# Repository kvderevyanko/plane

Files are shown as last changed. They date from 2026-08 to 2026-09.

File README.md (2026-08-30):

# LR1600 — FPV aircraft CAD project

Параметрический проект самолёта LR1600. Базовая единица геометрии — миллиметр.
Единственный редактируемый источник инженерных параметров —
`config/aircraft.yaml`; подробности геометрии крыла — в `docs/wing.md`.
`generated/` и `build/` содержат только производные артефакты; универсальный
CAD toolchain — в `cad/`.

## Быстрый запуск

```bash
./tools/build.sh
./tools/test.sh
```

Команды используют локальное окружение `.tools/conda/lr1600-cad` и создают
только воспроизводимые файлы в `build/`. Если окружение ещё не создано, см.
`environment/README.md`.

Перед физическим производством прочитайте `docs/laser-workflow.md` и выполните
проверки. Успешный экспорт не является разрешением на резку.

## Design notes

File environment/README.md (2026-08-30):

# CadQuery environment

`environment.yml` is the reproducible specification for CadQuery and the
libraries actually used by this project. The project-local prefix is
`.tools/conda/lr1600-cad` and is intentionally ignored by Git.

Create it without touching system Python:

```bash
CONDA_PKGS_DIRS="$PWD/.tools/conda/pkgs" \
  /home/kirill/miniforge3/bin/mamba env create --prefix "$PWD/.tools/conda/lr1600-cad" \
  --file environment/environment.yml
```

The convenience scripts select this prefix. No `conda init` is required.

For the reproducible airfoil-analysis executable on Linux amd64, run:

```bash
bash ./tools/bootstrap-xfoil.sh
```

It downloads the pinned Debian XFOIL 6.99.dfsg+1-3 package, verifies its
documented checksum, and extracts it only into ignored `.tools/apps/xfoil`.

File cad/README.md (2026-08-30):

# CAD source

Source models live here; output belongs only in `build/`. `common/` contains
calibration geometry, while `wing/`, `fuselage/`, and `tail/` are reserved for
aircraft assemblies. Every model must use millimetres.

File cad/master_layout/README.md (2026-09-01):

# Master-layout reference model

`model.py` creates a visual CadQuery reference of configured aircraft geometry
and, when supplied, selected commercial-hardware installation envelopes from
`config/hardware.yaml`.  It uses the common aircraft
coordinate system: root leading-edge datum at `(0, 0, 0)`, `+X` aft, `+Y`
right, and `+Z` up, in mm.

The thin rendered wing is not a structural skin model; its `0.25 mm` display
thickness only makes CadQuery tessellation deterministic.  The model never
adds a fuselage skin or inferred component volume.

The typed rough-field reference adds only wheel/floor envelopes, main-gear
hardpoint points, the 13-in propeller-clearance cases and three forward
tail-linkage route lines.  None is production gear/linkage CAD or a
structural/load release.

MAC and its leading-edge position are read via the corresponding `WingConfig`
properties.  The trapezoid matches the existing centred planform.  A CG band
is drawn only when the typed `cg.initial_envelope.status` is
`initial_design_assumption` and has both configured MAC fractions.  Generated
PNGs are disposable downstream inspection artifacts.

Commercial envelopes are bounding boxes or a propeller disk, not detailed CAD
models, fuselage skin, or procurement approval. The high-current route and
antenna keep-outs are display references only. The selected battery is
deliberately *not* added as a clearance-passed hardware envelope: its rail,
hatch and removal path remain blocked pending defensible CG/mass-moment
closure. The pre-existing aircraft-config battery study envelope remains
visible and is not a claim that a physical pack can be removed.

Explicitly `known` mass-ledger entries appear as labelled coordinate markers.
They are point references only, not inferred physical envelopes. `tbd` entries
are intentionally omitted from the drawing and remain visible through the
mass-properties calculator's unresolved list.

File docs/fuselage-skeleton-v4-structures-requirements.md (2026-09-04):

# LR1600 Fuselage Skeleton & Longeron Convergence v4 — structural contract

**Scope:** dry-fit CAD gate for the plywood/carbon basic skeleton only. This is not a release of the complete fuselage, gear, battery installation, motor installation, or boom clamps. It retains the v3 mass topology and the station set in `config/aircraft.yaml`; it does not give credit to the foam shell, tooling, or any later subsystem.

The active assembly is the two lower keel/shear webs, two side shear webs, eight transverse formers at X = -285, -170, -55, +65, +130, +200, +285 and +365 mm, any hatch rail strictly needed to avoid an open skeleton, and four actual 5 x 3-mm carbon longerons. Every listed plywood body shall be a placed extrusion of the exact kerf-free profile exported to DXF. A CAD construction box, a face-only placeholder, or a generic mate record cannot satisfy this contract.

## Datum and stock convention

Aircraft coordinates are X aft, Y starboard, Z up. The current 5 x 3-mm stock orientation is fixed for this pass:

| Stock dimension | Aircraft direction | Nominal extent |
| --- | --- | ---: |
| length | X | lower: -475…+365; upper: -170…+410 mm |
| 5-mm face | Y | 5.0 mm |
| 3-mm face | Z | 3.0 mm |

Thus a longeron feature may not silently rotate the stock to 3 mm in Y and 5 mm in Z. CAD shall expose the final solid cross-section at every support. Nominal saddle/slot sizes equal nominal stock and sheet thickness; laser-fit clearance is established only by the existing material/kerf coupon at CAM.

## Required Method-A build sequence

The following is the only accepted sequence for this subsystem. The CAD validator must test the stated translation for each moving instance against the already-installed active solids at a sufficient set of intermediate poses. The final pose may contact only the feature-specific contacts named in its joint records.

| Step | Moving instances | Nominal insertion | Required final condition |
| --- | --- | --- | --- |
| A1 | `FUS-LONGERON-LOWER-L/R` | locate on datum jig; no skeleton present | Straight, continuous lower stock at final Y/Z datum. |
| A2 | each transverse former | descend in -Z onto/open around lower stock | Each lower notch admits its already-installed rail without forcing it; former remains removable before web closure. |
| A3 | `FUS-KEEL-L/R` | continuous +X threading from forward of their final X start | Each web passes every intended former feature without cutting through, bending, or moving a former. |
| A4 | `FUS-SIDE-L/R` | continuous +X threading from forward of their final X start | Each side web passes only its intended former features; the upper route remains unclosed. |
| A5 | `FUS-LONGERON-UPPER-L/R` | continuous +X translation from forward of X=-170 | Each rail traverses every aligned, top-open frame notch and reaches X=+410 as one uncut length. |
| A6 | only necessary hatch/closure rails | declared direction after A5 | No closure traps either upper rail before its full insertion. |

Equivalent paths are permissible only if they preserve A1–A6's key facts: lower rails precede surrounding plywood; complete upper rails enter after formers/webs; no rail is inserted through a closed captive hole. A start pose shall be outside every final active primary solid by at least the moving part's full cross-section. Report the number and spacing of sampled poses and the minimum non-permitted clearance; sampled final contacts do not count as a clearance failure when the named contact is geometrically correct.

## Longeron support and bond contract

Every support is an actual cut feature on an actual placed plywood instance, with a unique ID. A valid support record has:

- longeron instance ID and actual cross-section at the support;
- plywood instance ID and feature ID;
- support type (`lower_open_notch`, `upper_open_notch`, `web_land`, or `bonded_face`), world X interval, and whether it is critical;
- the contact faces, their contact length and width, calculated nominal bond area, and a no-overlap fit result; and
- the assembly step at which it is engaged and the compatible insertion axis.

### Lower pair

Because lower longerons are installed first, transverse-former features must be **bottom-open U notches** (or an equally open edge saddle) that can be descended over the rail in A2. A closed 5 x 3-mm rectangle is forbidden. The lower keel/webs subsequently threaded in A3 shall provide continuous real bond faces/support lands along their overlap with each lower rail. The final model must not represent a rail simply intersecting the web volume: a rail surface must meet a declared, non-overlapping plywood support face.

### Upper pair

Because upper longerons enter in A5, every former they traverse must have a **top-open** 5-mm-Y by 3-mm-Z edge notch/saddle. Its open mouth must remain clear throughout the +X insertion path; no laterally offset notch, closed hole, tab, crossbar, hatch rail, or adjacent web can obstruct the swept 5 x 3-mm prism. The side web must supply a declared continuous upper-edge land and/or a declared continuous vertical bond face. The former notches locate the rail; the side web land carries the distributed web-to-longeron bond. Their geometry must touch the carbon without CSG penetration other than the feature-specific bonded-face tolerance.

For either pair, the nominal local plywood ligament from a notch root to the nearest free edge/window shall be at least one sheet thickness plus 3 mm, and shall be reported at every station. Where the former carries a high-load continuity bay (+65…+200 gear, -55…+65 wing-transfer, +285…+365 boom/motor), the corresponding notch root must retain at least 6 mm of continuous plywood in the load-carrying frame rail; a window may not terminate at that root. These are geometry/handling minima, not a substitute for proof or material allowables. A smaller ligament is a v4 skeleton blocker unless a dedicated local structural analysis and a revised prototype proof plan are supplied.

### Continuity requirements

The machine report shall sort supports by X and calculate unsupported intervals between their *contact intervals*, rather than claim a continuous land from a part name. Acceptance is:

- maximum unsupported gap <=10 mm outside critical bays;
- zero unsupported gap in X=-55…+65, +65…+200, and +285…+365 mm;
- no square-ended support/bond interruption inside a critical bay; and
- no discontinuity at a former caused by a window, slot, or different local placement.

The lower paths must be covered through X=-475…+365 and upper paths through X=-170…+410. End regions may taper only outside critical bays and must state remaining bond/contact length. No strength allowable is to be inferred until existing carbon-to-prepared-birch coupons have been tested. Expected first failures remain bond peel at an unprepared charred edge, plywood splitting at a notch root, or local carbon crush from an overly narrow caul—not global carbon tensile failure.

## Former-to-web joint contract

The active baseline contains **30** former/web through-joints if current web extents are retained:

- eight formers x two lower keel/webs = 16 joints;
- seven formers at X=-170…+365 x two side webs = 14 joints.

`FUS-FMR-X-285` has no side-web joint while present side webs start at X=-170; this absence must be explicitly recorded, not represented by an orphan feature. If CAD changes a web extent, it must update this expected joint count and explain the structural consequence.

Each of these 30 joints requires one exact instance-level record containing:

1. joint ID, tab-bearing instance/feature and slot-bearing instance/feature;
2. joint type, structural purpose, nominal web thickness and receiver-slot narrow dimension;
3. final world centreline/face coordinates and tolerance used;
4. declared insertion direction and assembly step;
5. remaining ligament on both members; and
6. exactly bounded permitted tab engagement/contact volume.

The continuous web may furnish a locally named through-tab at a station, but the CAD profile must contain distinguishable geometry for that feature; the label `perimeter-tab` alone is not sufficient. The former slot must be the specific profile cutout at the same world Y/Z location. In particular, a local 2-mm slot dimension does not establish mating until placed web and former feature centres/planes agree in world coordinates.

For a 2-mm web, the slot narrow dimension is 2.0 mm nominal. A 3-mm former may receive that same 2-mm web: former thickness is along X and does not change web/slot mating thickness. Tabs and slots are registration and shear transfer only after prepared bonded faces are present; do not credit an isolated thin tongue as a primary load path. No tab may terminate at a window corner or leave zero-width material. Every actual tab and slot participates in exactly one active joint, except a separately labelled jig-only feature; there must be zero duplicate counterparts and zero active orphan features.

## Collision and dry-assembly gate

The active-v4 collision set is restricted to placed formers, placed keel and side webs, active hatch/closure rails if any, and four carbon solids. Gear, nose, battery, wing, motor and boom items must be excluded by explicit subsystem filtering, not by whitelisting their collisions.

For each final or intermediate pose, classify contact only by a narrow feature-level permission:

- a named tab/slot engagement;
- a named carbon saddle/bond face;
- a named plywood bonded lap/butt face; or
- a named datum-jig contact during A1 only.

Whole-part-pair permissions are prohibited. All other active primary-primary intersections greater than 0.01 mm3 fail. The report must list both IDs, pose/step, intersection volume, and either contact ID or `UNEXPLAINED`. Acceptance total is **zero** `UNEXPLAINED` intersections. Face contact with zero volume is acceptable only if named in the contact record.

The results must include a machine-readable manifest and readable report with 30-joint accounting; each longeron support/bond interval and gap; all six Method-A paths; and collision classifications. It shall also export diagnostic views of full skeleton, one lower notch, one upper notch, one former/web joint, and any failed collision.

## Prototype-cuttable rule for v4

A skeleton part may be labelled **`PROTOTYPE CUTTABLE — SKELETON SUBSYSTEM ONLY`** only when its own profile/STEP identity, placed feature mates, ligaments, insertion path, and active collision checks pass. This grants only a first dry-fit/proof skeleton article. It does not release complete fuselage or change authoritative 398-g aircraft ledger.

Before adhesive is mixed, retain existing kerf calibration coupon and pass sacrificial 5 x 3-mm stock through all four real routes. Remove laser char to sound birch on every structural bond face, abrade/de-dust carbon, and record actual adhesive/cure procedure. Failed fit is corrected in CAM kerf settings or nominal source geometry as appropriate; it is never corrected by filing an untracked primary feature.

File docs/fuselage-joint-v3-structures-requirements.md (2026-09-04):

# LR1600 Fuselage Joint & Assembly Convergence v3 — structural-joint requirements

**Status: engineering input to CAD convergence; not a cutting release.**  This
note freezes the v2 mass architecture as a 457.997-g candidate.  Added mass up
to 20 g is justified only where this note calls for an actual bearing land,
tab, doubler, retainer, or local load-transfer feature.  Kerf remains a laser
job setting; no kerf offset belongs in the nominal profiles.

The source constraints are `config/aircraft.yaml`, `docs/landing-gear.md`,
`docs/fuselage-proof-plan.md`, and the v2 gate record.  In particular, the
main box must survive one-main 121 N vertical and 35 N lateral/longitudinal
proof; the nose index must survive 60 N vertical and 35 N lateral/
longitudinal proof; P60B restraint proof is 44.4 N in each principal direction.

## Non-negotiable CAD contract

For every physical joint the model shall carry a machine-readable record with:

- a unique joint ID, each actual instance ID, one tab/key/bond-face feature ID
  on each participant, station, nominal material thickness, and insertion
  axis;
- a joint type (`through_tab`, `blind_notch`, `bonded_saddle`, `clamp`, or
  `bearing`), structural purpose, and permitted overlap/contact volume; and
- a declared dry-build step.  A part may enter only while its insertion path is
  clear of parts already installed, apart from the joint's declared contact.

At nominal geometry, a tab thickness shall equal the receiving sheet's nominal
thickness and the slot's narrow dimension shall equal that thickness.  The
laser-process clearance is applied downstream after the 2-mm/3-mm coupons are
measured.  A joint is invalid if it is metadata only, uses a generic rectangle
unrelated to a counterpart, leaves a zero-width ligament, or needs a forced
elastic deformation to assemble.

The validator shall report, per joint: feature existence; one-to-one partner;
nominal width/thickness match; placement alignment; translated insertion-path
clearance; and residual ligament.  It shall also report every primary-solid
intersection.  Only declared tab/slot material, declared bonded faces, and
declared clamp/bearing contacts are permitted; unexplained intersection volume
above 0.01 mm3 is a failure.  Generic quantity placement by an arbitrary Y
increment is prohibited: each left/right, fore/aft or stacked instance needs
its own physical placement and role.

## A. Skeleton and longerons

Use the existing station set `-285, -170, -55, +65, +130, +200, +285, +365`
mm.  Each transverse former must have real, paired features to the longitudinal
members it actually stabilises; do not cut full-width members across the
230 x 125-mm hatch opening.  A former-to-keel/side-web tab may be sacrificial
for alignment, but it cannot be credited for primary shear unless it has a
continuous surrounding ligament and bond land.

Choose one coherent assembly method: **recommended Method A** is lower
longerons on the datum jig, central formers/keels and side webs located around
them, then upper longerons installed through open aligned notches before the
hatch/closure rails close the path.  The model must prove this order.  It may
not mix a closed captive slot at one station with a slide-through procedure.

Each 5 x 3-mm carbon longeron requires a real 5-mm-wide by 3-mm-deep locating
groove/saddle or an explicitly open insertion notch, with a continuous plywood
bond face.  The lower pair remains X=-475…+365 and the upper pair
X=-170…+410.  No unsupported gap or square-ended support interruption is
allowed in the gear bay, wing-transfer bay, or motor/boom bay.  The CAD report
shall list, for each of four paths, start/end, every supporting part,
uninterrupted bond-face length, and the largest unsupported gap.  Acceptance:
no gap in those critical bays; any non-critical gap is <=10 mm and explicitly
explained.  The actual 5 x 3 solid must clear the receiving geometry except
for its declared saddle/bond contact and must pass the full declared insertion
translation.

## B. Main-gear cassette

The cassette is a closed, serviceable double-shear assembly between X=+65 and
+200, tied to both lower longerons.  It needs separately identifiable port and
starboard doublers, front and aft spreaders, upper and lower closure/load-path
webs, and two real clamp lands.  Every spreader/closure must tab into its web
or be a clearly documented bonded lap with adequate overlap; an intersecting
solid is not a joint.  The load path to show in CAD is wheel/leg root -> clamp
lands and side doublers -> front/aft spreaders and closures -> lower longerons
and adjoining shear webs.

Use an explicit *single-leg specimen* solid, with root width, clamp length and
bolt centres stated in the manifest.  The clamp pocket reference gap shall be
4.0 mm.  The only valid variant stacks are:

| GFRP specimen | Total shim in pocket | Check |
| --- | ---: | --- |
| 4.0 mm | 0.0 mm | 4.0 + 0.0 = 4.0 mm |
| 3.5 mm | 0.5 mm | 3.5 + 0.5 = 4.0 mm |
| 3.0 mm | 1.0 mm | 3.0 + 1.0 = 4.0 mm |

If shims are split across faces, their sum—not their nominal part label—must
meet the table.  A shim must never be fitted to the 4.0-mm leg or stacked such
that the assembly exceeds the pocket gap.  Generate three mutually exclusive
validation configurations; they are not simultaneously installed.

For each clamp fastener, emit the actual hole diameter, centre-to-each-free-
edge distance, net ligament in load direction, plywood thickness at the hole,
bearing-land width, washer/spreader outside diameter, and whether the leg is
between two real shear plates.  The washer envelope must remain on solid
material; it may not bridge a window, slot or thin remnant.  These values are
inputs to the proof article, not a substitute for the required 121/35/35-N
test.  Main-leg replacement acceptance: remove clamp hardware, translate the
leg along the stated axis out of the cassette, insert each specimen, and
reinstall hardware with all fuselage primary parts remaining installed.

## C. Fixed nose index

The nose module at X=-285/-170/-55 shall contain a physically modelled metal
tang envelope, a plywood index block, two actual doublers, capture bolt/pin,
clearance at the bolt head/nut, and a removal direction.  The 12-mm key is
acceptable only if a 12-mm-wide tang has two flats engaging matching plywood
index faces.  The bolt retains the strut; it is not the yaw reaction feature.

The validator shall show: tang translated through the hatch/insertion path to
the seated position; zero forbidden overlap; the two key flats bearing on the
index faces under either yaw sense; capture hardware installed after seating;
and reverse translation after hardware removal.  Report capture-hole diameter,
edge distances, local bearing land, remaining ligament and expected first
failure (key-face crush, plywood split, or bolt-bearing migration).  The proof
gate remains 60 N vertical then 35 N lateral and 35 N longitudinal.

## D. Battery bay and hatch

The 155 x 75 x 28-mm P60B dummy must be the solid used for all positions:
X=-387.5, exact 24% target, wheels-25% target, -370 nominal, and -332.5 mm.
At each position report collision-free status against every structural part;
rail support and declared stop contact are allowed contacts, not blanket
exemptions.  Include a conservative connector/service envelope and state its
dimensions and side of exit.

Forward stop, adjustable aft stop and both strap anchor paths must attach to
real rails/formers/webs through actual tabs, bolts or bonded faces.  The model
must show accessible buckle/strap routing and access to tighten/release the aft
fine clamp.  Neither hatch, pack shrink-wrap, wiring nor a printed part gets
structural credit.  The complete path for each independent stop/strap path is
required to be capable of the full 44.4-N proof reaction.

Removal must be checked as individual poses, not a union-box reservation:
installed -> connector-service displacement -> +Z 20 -> +Z 50 -> +Z 100 ->
clear of the real 230 x 125-mm hatch.  Check all five rail positions or explain
why a worst-case pair bounds the others.  Each pose must be collision-checked
against hatch rails, formers, longerons, stops, avionics reservations and the
connector envelope.  Do not suppress a member class globally; every permitted
contact must name the physical contact face.

## E. Wing transfer, motor and booms

At the present wing-interface stations, show discrete plywood frames/webs and
any necessary local 3-mm doublers transmitting fuselage-side wing reactions to
both upper and lower longerons plus adjacent side webs.  Do not create a solid
plate/box in lieu of these parts.  This CAD task does not approve the wing; its
interface remains conditional on the existing wing proof.

The motor crossmember must be an assembly of laser parts: crossmember members,
real slots/tabs into longeron-connected structure, a central cable/cooling
opening, and a removable plate with a candidate motor envelope.  Plate bolts
must be accessible and the plate must translate aft (or another explicitly
stated direction) without prop-adapter trapping.  The provisional proof screen
remains 15.1 N axial, 1.26 N m torque and 0.64 N m inertia bending; a single
thin tongue, adhesive-only feature or printed tab may not be credited for
torque.

At X=+285/+365 and Y=+/-230, boom placeholder frames must be actual placed
profiles with no collision with longerons or the motor structure.  They remain
`NOT RELEASED`; no tube/saddle clamp load or mass credit is permitted until
tube, liner, fastener and coupon evidence exists.

## Required assembly record and CAD acceptance

The CAD package shall contain a stepwise dry-build record: lower-longeron jig;
central formers/keels; side webs; upper longerons; gear cassette; battery rails
and stops; nose index; wing-transfer closure; motor structure; remaining
closures/rails.  Each entry names inserted instance(s), axis, already-installed
collision set, joint IDs, adhesive timing and an alignment measurement.

Before structural prototype cutting, pass all of the following:

1. every declared tab and slot has exactly one real counterpart; no orphan;
2. all four real carbon solids fit and are installable by the single stated
   method;
3. all three gear-leg configurations insert/remove and satisfy their stack gap;
4. the keyed nose tang inserts/removes and has geometric anti-rotation faces;
5. P60B placements and removal poses pass without unexplained collision;
6. motor plate removes and all primary contacts/overlaps are classified; and
7. contact report has zero unexplained primary overlaps above 0.01 mm3.

Only parts whose own interfaces pass may be marked `PROTOTYPE CUTTABLE`.
Passing CAD permits cutting a proof-test structural prototype, not flight use;
proof coupons and installed proof remain required.

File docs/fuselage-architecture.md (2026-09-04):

# LR1600 Fuselage Architecture v1

**Status:** preliminary structural architecture and packaging estimate, not production CAD, a measured mass, material allowable, or flight release. All stations use the wing-root-LE datum; +X is aft. The 2,600-g integration case is used. Wing geometry and its structural concept are unchanged.

## Selected architecture and envelope

Selected: a repairable plywood-frame/four-longeron semi-monocoque fuselage. Laser-cut internal structure, local birch hardpoint boxes and continuous carbon longerons carry load; removable foam/light-composite shell, hatches, printed camera bezel and printed cable guides are secondary. None of those secondary parts receives wing, boom, motor, battery or landing-load credit. A 14-g lower skid is sacrificial and replaceable.

Preliminary outer envelope is **X=-500 to +410**, W=**180** (Y=+/-90), H=**190** (about Z=-95...+95); a replaceable motor plate reaches X=+430. The 910-mm body prioritises serviceability and no-ballast CG closure over minimum frontal area. This nose length is an explicit pitch-inertia penalty, not an aesthetic choice.

| Station X | Function | Primary material |
|---:|---|---|
| -285 | nose-gear / front lower-keel **partial U-web** station | 2-mm birch; printed camera bezel secondary |
| -170 | lower-keel / battery-side-rail **partial U-web** station | 2-mm birch/local non-ferrous fasteners |
| -55 | wing-forward shear frame | 3-mm birch web, 2-mm flanges |
| +65 | wing-rear shear frame / gear-box front | 3-mm birch |
| +130 | main-gear reaction frame | 3-mm birch double-shear box |
| +200 | gear-box rear / equipment frame | 3-mm web, 2-mm flange |
| +285 | boom/motor torque web | 3-mm birch/carbon-wrap interfaces |
| +365 | motor plate / boom-clamp frame | 3-mm birch and replaceable plates |

Intermediate shape formers are 2-mm birch. The **two lower 5x3-mm pultruded-carbon longerons** run continuously from X=-475 to +365, tying the forward battery-stop/keel box into the wing box; the upper pair runs X=-170 to +410. 2-mm birch side rails and the hatch perimeter are primary tension/shear members around the battery opening. Thus no battery stop discharges into unsupported shell. Exact supplier data, scarf detail and adhesive overlap remain coupon/CAD gates. Sand laser-charred structural bond faces to sound wood, abrade and de-dust. Nominal CAD contains no kerf compensation; a measured-kerf coupon controls finished slots.

## Primary paths

| Interface/event | Primary load path | Never primary |
|---|---|---|
| Wing attachment | wing root spar/D-box hardpoints -> paired 3-mm saddle/shear frames at -55/+65 -> longerons and central box | foam, hatch, one former, printed saddle |
| Twin booms | provisional indexed +285/+365 alignment and motor-bridge stations; final primary bending transfer remains a dedicated boom/wing-interface CAD and proof gate | adhesive-only tube joint, foam, one bolt |
| Main gear | GFRP leg -> +65/+130/+200 double-shear box -> lower longerons and upper closure web | shell, foam, printed fairing |
| Nose gear | strut bearing tube -> -285/-170/-55 lower-keel box -> lower longerons | camera tray/nose shell |
| Motor | fixed 25-g fuselage cross-member/base -> paired shear keys -> boom clamp frames and central torque web; separate replaceable plate/adapter then bolts to base | printed tab, thin tongue, adhesive alone |
| Battery | broad 2-mm cradle -> 3-mm end stops/two straps -> lower longerons and hatch-perimeter side rails | cells, shrink-wrap, hook-and-loop alone, hatch |
| Body bending/torsion | four longerons carry bending; plywood frames and local diagonal 2-mm webs close central box | foam shell alone |

Boom axes remain Y=+/-230, outside the 180-mm body. The fuselage supplies a central bridge and clamp frames, not a narrow wall carrying the full 460-mm separation. Use two indexed stations >=80 mm apart, non-crushing liners and two anti-rotation shear features per boom. Fixture axes/tail during bonding. Preliminary targets: each boom axis +/-0.5 mm at both clamps, station separation +/-0.5 mm, and differential tail incidence <=0.25 deg after proof.

## Battery and service access

The P60B 6S1P integration envelope is **155 x 75 x 28 mm**, a feasible two-cells-long by three-cells-wide 21700 arrangement including interconnect, insulation, connector exit and modest assembly allowance; it is not a verified pack drawing. The prototype rail has **55-mm** useful travel, X=-387.5...-332.5, extending the prior forward limit by 5 mm without lengthening the nose. With the fixed-nose gear ledger, required pack centres are -384.78/-373.40/-362.03/-339.27 mm for 24/25/26/28% MAC respectively. The X=-370.0 nominal reference yields 25.30% MAC; exact 24% and 25% are physically reachable. The complete moving pack envelope is X=-465...-255. Final measured-CG release is mandatory.

Use a top hatch with a provisional **230 x 125-mm clear opening** (approximately X=-472.5...-242.5), two mechanical latches and a secondary retained strap. Its CAD removal sweep clears the pack at both rail limits, but physical dummy-pack service proof remains required. No full-width former crosses this opening: the -285/-170 stations are lower-keel partial U-webs only, while the birch perimeter/side rails close the load path. The pack lifts up after guarded disconnect; it does not pass servo horns/high-current wire. Full-area non-compressive cradle, 3-mm stops and two 20-mm straps take the 6-g retention assumption with 1.5 proof: a 503-g pack needs **29.6 N operational / 44.4 N proof per principal direction**. Treat each complete stop/strap path as capable of the full proof load rather than claiming a failed path shares it. At nominal X=-370.0 the battery CG ledger moment is **-186,110 g mm**. Proof with an inert dummy in six directions.

FPV occupies a protected lower-front cassette centred at X=-215, Z=+5, vertically separated from the pack. Optional 25--60-g HD camera uses a removable tray centred at X=-175; its break-away printed cradle is not a nose-impact path. FC/equipment trays are X=+80...+210 with an upper service hatch. GNSS uses the non-ferrous upper support at X=-105, Z=+95; preserve a compass keep-out from the nose strut and high-current wiring.

## Materials and mass

| Group | Central mass g | Function |
|---|---:|---|
| 2-mm frame, keel, shear webs | 70 | primary shape/shear/torsion |
| Carbon longerons/local wraps | 34 | primary bending continuity |
| 3-mm birch wing/gear/boom hardpoints | 70 | bearing/clamp/concentrated reactions |
| Foam/light-laminate shell and extended-nose reinforcement | 62 | enclosure only; local bumper support |
| Battery cradle, rails, hatch, straps/latches | 55 | retention/service |
| Fixed motor base/cross-member | 25 | fuselage-side primary interface; excludes removable plate/adapter |
| Equipment/camera trays | 18 | secondary support |
| Replaceable skid/bumper | 14 | ground protection |
| Adhesive, inserts, fasteners, chafe allowance | 50 | installation allowance |
| **Fuselage structural group, no removable gear** | **398** | **design estimate** |

The single point submitted to the current CG ledger is **398 g at X=-1.6 mm** (moment -636.8 g mm), not measured. The removable motor plate/adapter/positive prop-retention group is a separate **50-g propulsion-ledger item** and is explicitly excluded from this 398-g fuselage group; only its fixed 25-g base/cross-member remains here. Plausible mass interval is 365--440 g, driven by plywood density, carbon section, adhesive uptake, latches and proof outcome. Do not remove 3-mm gear/boom boxes or continuous longerons only to meet target mass. Expected early failures: plywood bearing/splitting, unprepared-bond peel, local carbon crushing at clamp, gear-leg root delamination and motor-plate bolt bearing; global foam-shell failure must remain non-critical.

## Motor and cooling interfaces

The fixed base accepts a separate replaceable 50-g plate/adapter/positive-retention group for the current 50-mm-diameter, 70-mm installed-length, <=180-g motor class without locking an SKU. The preliminary proof envelope is **15.1 N axial thrust** (1.5 x a 10.1-N screening thrust), **1.26 N m torsion** (1.5 x a 0.84-Nm screening torque), and **0.64 N m motor-inertia bending moment** (4 g on 180 g at a 90-mm CG offset). These are bounded design screens, not measured motor data. Before release, proof selected hardware to measured static thrust, 1.5 times measured torque and 4-g motor inertia at true CG offset; inspect plate twist, bolt bearing, clamp slip, carbon crushing and prop alignment.

Provide a baffled lower-front inlet for battery/FC, a protected side inlet at X=+190 for ESC/regulator flow, and upper/aft outlets at X=+275...+340. Outlet free area >=1.25x inlet after guards. Recessed mesh is allowed only when temperature testing shows acceptable pressure loss; exits must not ingest grass. Use grommets, strain relief and removable covers at all wire/antenna penetrations.

## Release gates

1. Coupon actual birch bearing/net-section, carbon clamp liner and prepared bond, then proof a representative wing/boom/gear bay.
2. Proof installed main/nose hardpoints vertically and laterally to `landing-gear.md`, with no permanent set, slip, cracking, delamination or incidence loss.
3. Proof battery cradle/rails/stops/latch in six directions; repeat removal after proof.
4. Demonstrate dummy-prop clearance at maximum compression, 20-mm rut and 8-deg tail-low attitude.
5. Enter weighed parts and measured CG before calling the integration case a flight release.

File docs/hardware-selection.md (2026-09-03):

# LR1600 hardware baseline v1

> Superseded for active fuselage/gear integration by
> [`config/hardware.yaml`](../config/hardware.yaml) and
> [`cg-integration-v2.md`](cg-integration-v2.md). This retained document is
> historical evidence for the rejected 14-in/KDE/P30B branch, not a current
> component selection or mass source.

Status: selected preliminary hardware, **not** a procurement release. Aircraft
requirements remain in `config/aircraft.yaml`; exact commercial facts, masses
and installation envelopes have one versioned source: `config/hardware.yaml`.
Every commercial source was retrieved on 2026-09-01.

## Propulsion

| Item | Preliminary selection | Evidence and disposition |
|---|---|---|
| Propeller | APC LP14010E / 14x10E Thin Electric, two blade, 34.02 g | [APC](https://www.apcprop.com/product/14x10e/) gives geometry, mass and hub. [UIUC Volume 4](https://m-selig.ae.illinois.edu/props/volume-4/propDB-volume-4.html) provides Ct/Cp/efficiency data. |
| Fallback prop | APC13010E / 13x10E | [Horizon/APC listing](https://www.horizonhobby.com/product/electric-propeller-13-x-10e/APC13010E.html); lower-clearance fallback, but less convincing 90-km/h forward-flight screen. Not in the mass baseline. |
| Motor | KDE Direct KDE4215XF-465 | [Manufacturer](https://www.kdedirect.com/products/kde4215xf-465): 465 KV, 4–6S LiHV, 195 g bare, 48.2 x 36 mm, 62 A / 1375 W for 180 s with >=5 mph cooling. |
| ESC | Hobbywing Skywalker 60A V2 / 30216101 | [Official manual](https://www.hobbywing.com/en/uploads/file/20250930/64b726be7a56c9f415385f77683cdc46.pdf): 3–6S, 60 A continuous, 80 A peak, 68 g, 73 x 30 x 12 mm. Integral 5-V BEC is unused. |

The APC 14x10E central forward-flight screen is about
4.5/4.9/5.58/6.27 krpm at 60/70/80/90 km/h. Pitch speed is
68.6/74.7/85.0/95.5 km/h and tip speed 83.8/91.2/103.9/116.6 m/s. These are
kinematics, not a safe-RPM approval. The 490/670-W electrical screen uses a
static-coefficient proxy around 6.6/7.33 krpm and 26/32 N only.

KDE has no manufacturer map for a 6S APC14x10E pusher combination. Before
purchase or flight, bench-test current, RPM, thrust and motor/ESC temperature
in the installed pusher geometry; capture the current APC RPM limit too. True
pusher installation has APC lettering facing aircraft front and a positively
retained, nutted adapter. Motor reversal cannot correct a prop mounted with
the wrong airfoil face.

The 14-inch disk remains in the 460-mm boom-spacing screen; 15 inch remains
excluded from baseline until a new geometry/dynamic-clearance analysis.

## Battery and protection

Selected preliminary cell is [Molicel INR-18650-P30B](https://www.molicel.com/wp-content/uploads/Product-Data-Sheet-of-INR-18650-P30B-80111-1.pdf), not a marketplace cell. A 6S2P pack gives:

| Quantity | Value |
|---|---:|
| Typical nominal / 80%-usable energy | 129.6 / 103.68 Wh |
| Complete pack estimate | 624 g = 564 g cells maximum + 60 g construction allowance |
| 685-W screening load at 21 V | 32.62 A pack / 16.31 A per cell |
| Documented cell continuous limit | 30 A to 80 °C cutoff |
| First-order 50%-SOC cell-only sag | 0.277 V/cell; 1.66 V/6S |

The documented 17-mOhm DCIR is used only for the 50%-SOC cell calculation;
low-SOC, temperature, ageing, busbar and connector effects need a pack
load/sag/temperature test. 6S3P is a 150-Wh stretch (194.4 Wh typical,
155.5 Wh at 80%, roughly 926 g with construction allowance) and remains a
mass-risk alternative.

Architecture is balance-charge/monitoring-only with thermal sensing; there is
**no power-path BMS between pack and ESC**. A BMS transient disconnect is a
single-point propulsion loss. The future flight path is pack positive → fuse →
anti-spark/main disconnect → current sensor → ESC plus independent regulators.
Exact fuse, anti-spark connector, BMS and time-current validation remain TBD.
The [Littelfuse MEGA family](https://www.littelfuse.com/assetdocs/littelfuse-datasheet-mega-32v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) is a family reference, not a selected fuse.

## Controls and avionics

Baseline control count is two aileron, one elevator and two rudder servos:
four Hitec [D85MG](https://hitecrcd.com/d85mg-micro-32-bit-metal-gear-servo/)
at 21.9 g, 4.3 kgf-cm and 2.15-A stall each, plus Hitec
[HS-7245MH](https://hitecrcd.com/hs-7245mh-high-voltage-high-torque-metal-gear-coreless-mini-servo/)
at 34 g, 5.2 kgf-cm and 1.6-A stall. Aggregate hard stall is 10.2 A / 61.2 W
at 6 V: an electrical transient, not an average-power claim. Hinge-moment and
load-path validation are still required.

Dedicated 6 V is [Pololu D24V150F6](https://www.pololu.com/product/2882),
thermal-dependent 15 A nominal / 32-A instantaneous. Clean 5 V is
[Pololu D24V90F5](https://www.pololu.com/product/2866), thermal-dependent
4–8 A. Both need installed thermal validation; neither ESC BEC nor FC BEC
replaces the separated-rail design.

| Function | Preliminary selection |
|---|---|
| FC | Matek H743-WING V3, [manual](https://www.mateksys.com/downloads/H743-WING_Manual.pdf), 30 g; H743 WING family is [ArduPilot supported](https://ardupilot.ardupilot.org/plane/docs/common-autopilots.html). |
| GNSS/compass | Matek [M10-5883](https://www.mateksys.com/?portfolio=M10-5883), 9 g; keep >=100 mm from power/ESC/motor/ferrous parts; M10-L4-3100 fallback after failed compass survey. |
| RC | RadioMaster [RP3 Diversity ELRS](https://www.radiomasterrc.com/products/rp3-expresslrs-2-4ghz-nano-receiver), CRSF UART, 4.6 g. |
| Telemetry | Holybro [SiK V3](https://holybro.com/products/sik-telemetry-radio-v3), 23.5 g; legal 433/915 band TBD. |
| Airspeed | Matek ASPD-DLVR, 4 g; [compatibility source](https://www.mateksys.com/?page_id=7637), primary manual still required. |
| FPV | RunCam [Phoenix 2 Nano](https://www.runcam.com/download/Phoenix2-Nano/Phoenix_2_Nano_Manual_EN.pdf), 5 g; TBS [Unify Pro32 HV](https://www.team-blacksheep.com/media/files/tbs-unify-pro32-manual.pdf), 8.7 g. |

Hotel-load envelope is 7-W low, **16-W nominal** (hardware-backed design
estimate, not measurement) and 25-W high. GNSS/compass stays out of the
motor/ESC/high-current/VTX zones, receiver antennas are orthogonal and clear
of VTX, and VTX requires airflow plus legal setting. Provisional interfaces:
GNSS UART2 + I2C1, SiK UART7, CRSF UART6, airspeed I2C2; confirm the purchased
board revision before configuration.

## Gates remaining

- Motor–propeller pusher bench map, installed cooling and mount proof.
- Pack sag/temperature, fuse time-current, connector and anti-spark validation.
- Servo hinge moments, regulator transient/thermal test and linkage mass.
- Compass/RF survey, range, VTX legality/cooling and primary airspeed manual.
- Mass moments and actual battery/hatch geometry; current tray does not close CG.

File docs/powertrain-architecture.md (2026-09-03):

# LR1600 Powertrain Architecture, Battery & Avionics Packaging v1

> Historical 2,400-g energy screen. The active configuration is the P60B
> 6S1P / 13x10 preliminary integration branch in
> [`config/hardware.yaml`](../config/hardware.yaml); this document is not its
> mass or placement source.

`scripts/powertrain_architecture.py` is a reproducible architecture and
energy-screening model.  It writes `analysis/powertrain/summary.json` and
three inspection plots.  It does not select a motor, ESC, propeller, battery,
cell, connector, BEC or any commercial SKU.  `config/aircraft.yaml` remains
the sole editable aircraft source of truth; this document proposes only a
future typed-configuration contract after integration of the packaging study.

## Known

- Target aircraft mass is 2400 g.  The prior propulsion model has a central
  electrical propulsion reference of 135 W at 70 km/h and 197 W at 80 km/h;
  these are central CdA/efficiency cases, not measured flight powers.
- The existing requirement study uses 490 W as the adverse 4 m/s-climb
  integration screen and 670 W as a broader propulsion-only screen.  This
  study adds its nominal 15 W hotel estimate when calculating bus current.
- Twin-boom spacing is 460 mm.  The preceding clearance work admits 12--14 in
  study disks; 15 in does not fit the baseline geometry without a change.

## Design assumptions

- 4S uses 14.0 V and 6S uses 21.0 V as conservative loaded-voltage screen
  inputs.  Their fully charged voltages are 16.8 and 25.2 V.  These are not a
  pack discharge curve: selected cells must provide `V(SOC, I, T)`.
- Bus hotel low/nominal/high cases are 7 / 15 / 25 W at the battery terminals.
  They include estimated DC/DC loss, but no measured hardware consumption.
- The power lead study uses 0.5 m one way, 2 mOhm connector-pair resistance,
  copper resistivity 0.01724 ohm-mm²/m and a 2% wire-only loss target.
- Usable energy is 80% of nominal stored pack energy.  This is a reserve and
  unusable-energy study assumption, not a flight reserve policy.

## 4S versus 6S

At equal electrical power, 6S reduces current; it therefore reduces I²R lead
and connector heat, and enables the lower-KV motor region normally useful for
the existing 12--14 in pusher study.  This is not a claim that more series
cells are always better: 6S needs a 25.2-V-charged ESC and appropriate BEC/DC
converters, whereas 4S can use lower-voltage hardware.

| Case (includes 15 W nominal hotel) | Bus power | 4S current at 14.0 V | 6S current at 21.0 V |
|---|---:|---:|---:|
| 70 km/h central cruise | 150 W | 10.7 A | 7.2 A |
| 80 km/h central cruise | 212 W | 15.1 A | 10.1 A |
| 490 W climb integration screen | 505 W | 36.1 A | 24.1 A |
| 670 W broader screen | 685 W | 48.9 A | 32.6 A |

At the final broad screen, a 0.5-m one-way pair needs about 3.0 mm² copper
on 4S or 1.3 mm² on 6S to hold wire-only loss at 2%.  With a conservative
2.5-mm² study lead, losses are about 16.5 W (4S) and 7.3 W (6S), respectively;
connector-pair heat adds about 4.8 W and 2.1 W.  Harness length, temperature,
connectors and actual current must replace this screen before wire selection.

### Preliminary architecture direction

Use a **6S propulsion bus as an initial design assumption**, not a hardware
selection.  It makes the 670 W screen roughly 33 A instead of 49 A, giving a
meaningful margin in wiring, connector heating and Li-ion parallel-count
choices.  4S remains a fallback if actual motor/propeller mapping or packaging
evidence overturns this benefit.

## Propulsion motor and ESC requirements

The preferred propeller geometry and motor-map analysis remain separate from
this electrical calculation.  Electrical integration constrains their search:

- motor/propeller must demonstrate the 12--14 in clearance-compatible
  operating point, 60--90 km/h pitch-speed coverage and the propulsion study's
  actual thrust-versus-airspeed requirement;
- with a 6S bus, validate a lower-KV motor operating region rather than a
  catalogue maximum-W number; RPM, torque, shaft pattern and thermal map are
  still TBD;
- request at least 35 A measured installed continuous current capability and
  45 A short burst capability at 6S, with verified margin above 25.2 V;
- ESC cooling is a packaging requirement: it needs direct ram/ducted airflow,
  a short high-current route and a thermal demonstration at its installed
  location.  Telemetry is desirable for current, voltage, RPM/temperature if
  hardware supports it, but its protocol is TBD;
- active/freewheel control may reduce part-load ESC loss where supported; it
  is not assumed.  Prop braking must remain disabled unless its effect on a
  pusher installation, motor heating and recovery modes is tested.

Do not use an ESC BEC as the aircraft's assumed avionics supply.  Use a
dedicated 6-V servo regulator (provisionally at least 10 A continuous / 15 A
transient, pending servo count and measured stall currents) and an independent
clean regulated 5-V avionics rail.  This separates servo transients from FC,
GNSS, receiver and airspeed power.

## Hotel load and endurance sensitivity

The 7 / 15 / 25 W cases are **battery-bus continuous** design estimates.  The
servo group adds a separate provisional 48-W peak on its 6-V rail, which is a
BEC/transient test input and must not be counted as continuous endurance load
without a duty-cycle measurement.

At the central 70-km/h propulsion reference, the following are still-air
screening values, not promised endurance or range:

| Usable energy | Low 7 W: h / km | Nominal 15 W: h / km | High 25 W: h / km |
|---:|---:|---:|---:|
| 100 Wh | 0.70 / 49.2 | 0.67 / 46.6 | 0.62 / 43.7 |
| 150 Wh | 1.05 / 73.8 | 1.00 / 69.9 | 0.94 / 65.5 |
| 200 Wh | 1.41 / 98.5 | 1.33 / 93.2 | 1.25 / 87.4 |
| 250 Wh | 1.76 / 123.1 | 1.66 / 116.5 | 1.56 / 109.2 |

The generated result also includes all 60/70/80/90 km/h and low/nominal/high
combinations.  It uses `endurance = usable_Wh / (P_propulsion + P_hotel)`.
The previous propulsion model remains the authoritative place for its drag,
efficiency and headwind sensitivity assumptions.

## Li-ion versus LiPo battery direction

The study uses nominal **pack** specific-energy bands of 200--240 Wh/kg for
Li-ion and 150--190 Wh/kg for LiPo, then applies the common 80% usable-energy
assumption.  Thus a 200-Wh usable study system represents 250 Wh nominal and
roughly 1040--1250 g Li-ion or 1320--1670 g LiPo.  These are packaging/mass
study ranges, not actual pack masses.

| Usable energy | Li-ion estimated pack mass | LiPo estimated pack mass |
|---:|---:|---:|
| 100 Wh | 521--625 g | 658--833 g |
| 150 Wh | 781--938 g | 987--1250 g |
| 200 Wh | 1042--1250 g | 1316--1667 g |
| 250 Wh | 1302--1563 g | 1645--2083 g |

**Li-ion is the preliminary long-range direction**, conditional on data for
the actual cells, series/parallel grouping, low-SOC voltage sag and thermal
rise.  The 685-W broad screen is 2.3--5.8C at 250--100 Wh usable, respectively;
cell and parallel-count ratings must substantiate it.  **LiPo is the fallback**
when a suitably packaged Li-ion system cannot meet peak-current, sag or
temperature requirements.  Neither chemistry nor capacity has been selected.

## Typed source-of-truth assumptions adopted by integration

The integration has added the following preliminary assumptions to
`config/aircraft.yaml`.  They are requirements/envelopes, not selected
hardware or measured performance:

```yaml
propulsion:
  status: initial_design_assumption
  nominal_series_count: 6
  propeller: {diameter_min_mm: 330.2, diameter_max_mm: 355.6, pitch_min_mm: 228.6, pitch_max_mm: 254.0}
  motor: {kv_min_rpm_per_v: 365.0, kv_max_rpm_per_v: 570.0, continuous_current_a: 35.0, peak_current_a: 45.0}
electrical:
  propulsion_bus_nominal_voltage_v: 22.2
  propulsion_bus_loaded_min_voltage_v: 21.0
  avionics_logic_rail_v: 5.0
  servo_rail_v: 6.0
  hotel_load_low_w: 7.0
  hotel_load_nominal_w: 15.0
  hotel_load_high_w: 25.0
battery:
  chemistry_direction: li_ion_preliminary  # conditional on sag/thermal data
  usable_energy_preferred_min_wh: 100.0
  usable_energy_preferred_max_wh: 150.0
  mass_min_g: 520.0
  mass_max_g: 940.0
```

The source config separately carries a 100--150 Wh preferred packaging range
and 520--940 g conditional Li-ion mass envelope. The 100 Wh baseline maps to
521--625 g and the 150 Wh stretch case maps to 781--938 g using the explicit
80% usable fraction and 200--240 Wh/kg nominal-pack screen. That mass range
must not be treated as a procurement mass or a closed 2400-g mass budget; the
100 Wh case is the baseline and 150 Wh awaits mass/moment closure. The larger
200/250 Wh rows remain energy sensitivity cases rather than selected fuselage
requirements.

## TBD before hardware selection

- motor KV/RPM/torque map, propeller pitch/blade count and measured static and
  forward-flight thrust;
- selected cells/pack architecture, mass, dimensions, sag, thermal behaviour,
  BMS/protection, connector and charge policy;
- actual servo count, rail voltage, average/stall current, and BEC test data;
- exact FC/GNSS/RX/telemetry/VTX models, pin/resource map, radio frequencies
  and antenna geometry;
- final wiring lengths, conductor temperature rating, fuse/anti-spark choice,
  ESC/motor cooling, EMI/compass survey and installation tests;
- battery position range and resulting estimated configuration CG.

## Reproduction

```bash
./tools/cad-shell.sh scripts/powertrain_architecture.py
./tools/test.sh
```

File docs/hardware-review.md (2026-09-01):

# Independent review — hardware baseline v1

Review scope: evidence quality, ratings, battery model/protection, mass/CG,
and layout/removal honesty. Reviewer findings were dispositioned as follows.

| Finding | Disposition |
|---|---|
| Current X=0 ±30 mm tray cannot reach 24–28% MAC. | Accepted blocker. No new tray/hatch geometry is recorded; solver range and explicit no-closure output added. |
| 220.05-g central fuselage residual masks structural uncertainty. | Accepted. Low/central/high residual is now 389.96/220.05/50.14 g, so mass closure remains blocked. |
| CG documentation did not match generated calculation. | Fixed: current tray values are 166.15/173.95/181.75 mm. |
| Motor check implied evidence-closed capability. | Fixed: only partial KV/current screen passes; original mass envelope fails and 6S+APC operating point/continuous rating remain unvalidated. |
| Fixed-21-V sag calculation was not self-consistent. | Fixed with a cell-only constant-power root: 685 W at 21.6 V/102 mOhm gives 38.83 A, 17.64 V, 19.42 A/cell at 50% SOC. It increases the need for low-SOC/cold bench validation. |
| Prop map, FMEA, rail/servo authority, actual removal/collision are incomplete. | Accepted as procurement/fuselage gates. The analysis now labels prop data as a UIUC screening method and includes a three-motor shortlist; no false clearance, removal, hinge-moment or rail-thermal pass is claimed. |

Remaining high findings are therefore open, not waived: motor-prop pusher bench
map, APC RPM limit, ESC LVC/thermal behavior, pack build/sag/fuse test, FC
external-rail connection verification, rail-load/servo-hinge analysis,
compass/RF survey, real motor hub/adapter/wiring collision, and battery
retention/removal proof. The M10-5883 availability/EOL state must be checked at
procurement; its selected-preliminary status is not an availability guarantee.

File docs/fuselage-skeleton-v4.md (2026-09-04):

# LR1600 Fuselage Skeleton & Longeron v4 gate record

**Status: NOT CUTTABLE — v4 WIP retained.**  This document covers only the
basic skeleton and four 5x3-mm carbon longerons.  Gear, nose, battery, wing,
motor and boom systems were intentionally outside the gate.

## Independent CAD gate result

The active set has 12 plywood definitions, 12 placed instances and 30 declared
former-to-web joints (16 keel and 14 side).  DXF and STEP extrusion both derive
from `PartDefinition` for these active parts.  Those facts do not establish a
physical joint.

The independent CSG check found all 30 former/web joints overlapping in their
final placements, totalling about 886 mm3.  The v4 collision report hid them by
whole-part-pair permission rather than by an identified tab engagement volume.
Former extrusion direction and web-slot placement leave half the former through
the web; keel joints additionally have a Z mismatch.

Discrete independent translation sampling also finds both keel webs and both
side webs colliding with installed formers through their claimed +X insertion
paths.  Therefore Method A fails at the web-installation steps, irrespective of
the declared sequence metadata.

## Longeron-specific blockers

- Lower carbon-to-keel contact is a line contact, with no physical bond area.
  Claimed continuous support and 2,520-mm2 bond area per lower rail are not
  geometry-derived.
- Former notches engage only 1.5 mm of the intended 3-mm stock because their
  placed Z is offset from the declared feature.
- Upper rails can translate in sampled poses, but with zero nominal clearance
  and only 2-mm wide side-web contact; the reported 1,740-mm2/rail area is not
  supported by the solid geometry.

## Required corrective geometry

1. Generate the real tab/notch contours from the same placed feature datum as
   the report, then cut the exact nominal engagement without a whole-part
   collision whitelist.
2. Reposition or orient the former extrusion and each web so tab/slot volume is
   feature-specific and the non-engaged solid volume is disjoint.
3. Model bottom-open 5(Y)x3(Z) lower saddles and top-open upper saddles at the
   actual longeron coordinates; calculate support/bond area from faces.
4. Implement every Method A pose as a translated CSG collision check against
   the already-installed subset.  Report minimum clearance, not a metadata
   PASS.

Until these items pass, no active skeleton part has earned
`PROTOTYPE CUTTABLE — SKELETON SUBSYSTEM ONLY` and no dry-fit laser prototype
should be cut.

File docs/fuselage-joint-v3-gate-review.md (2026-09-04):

# Fuselage Joint & Assembly Convergence v3 — independent gate

**Status: REJECTED — complete plywood set is not cuttable.**

The v3 candidate preserved the lightened topology and reports 467.484 g, within
the 478-g joint budget.  This is not an accepted structural mass or centroid:
the assembly is not physically coherent.

## Independent deterministic findings

- 85 primary-to-primary intersections exceed 0.01 mm3; 63 have no declared
  mating relationship.  Intended contacts are not represented as feature and
  instance-level permissions.
- Former slots miss each longitudinal web in world coordinates.  The existing
  checks find a generic slot, not the stated feature, instance, alignment or
  remaining ligament.
- The four 5x3-mm carbon longerons have neither physical plywood saddles nor
  a valid insertion route: lower rods are separated from their keel webs and
  formers cut into the rods.
- Gear cassette pieces overlap rather than form a closed cassette.  There are
  no configured GFRP-leg solids, valid 4.0-mm pocket/shim stacks, bearing
  report, hardware envelope or replacement sweep.
- The nose tang/index and capture fastener are metadata rather than solids;
  index/doublers overlap.  Geometric anti-rotation and removal are unproven.
- Battery solid clears its five installed X positions, but rails, stops,
  anchors, clamps, strap/hardware access, connector and avionics service
  envelopes lack a real attached assembly.  Removal checks only the rail ends.
- Wing-transfer members are absent.  Motor plate and crossmember are separated
  by 39 mm; boom placeholders are absent from the placed assembly.
- Adhesive mass uses a fourfold longeron-land expression and must be recomputed
  only after real bond faces exist.  Generic structural-hardware ownership
  cannot yet be reconciled against landing-gear hardware.

## Required next geometric work

Replace the present profile/placement abstraction with feature-level geometry:
every actual tab, notch, saddle, bolt land and key needs an instance-level
counterpart, permitted contact volume and insertion path.  Then derive an
unexplained-collision report, a true sequential dry assembly, and only then
recalculate mass and centroid.  No part currently labelled `PROTOTYPE CUTTABLE`
has passed this gate.

## Checks performed

- `./tools/test.sh`: 166 passed, but declarations-only tests do not prove the
  listed physical conditions.
- `git diff --check`: passed.

Physical coupons/proof tests remain later gates; this rejection is based only
on resolvable CAD geometry and assembly conditions.

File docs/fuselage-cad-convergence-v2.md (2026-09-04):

# LR1600 Fuselage CAD Convergence v2 — gate record

**Status: NOT RELEASED — corrective WIP.**  This record deliberately does not
replace the `fuselage_structural_group` ledger entry (398 g) or its moment.

## Reconciliation snapshot

| Item | Mass (g) | Status |
| --- | ---: | --- |
| Architecture ledger estimate | 398.000 | Authoritative integration estimate; unchanged |
| WIP before convergence | 676.136 | Divergent profile/box model; invalid |
| Current profile-derived candidate | 457.997 | Not accepted for aircraft CG or manufacture |

The current candidate is 218.139 g below the WIP number.  Its derived
breakdown is 336.742 g birch, 66.030 g 5×3-mm carbon longerons, 20.225 g
adhesive allowance from 61,744 mm² declared bond land, and 35.000 g hardware:
16 g structural fasteners, 8 g hatch hardware, 6 g battery retention, and 5 g
fixed motor-interface hardware.  The removable motor plate/adapter is excluded
from this candidate because it is owned by the propulsion ledger.

The candidate centroid is X/Y/Z = -5.072 / +0.113 / -14.753 mm.  This value is
finite and mechanically derived from the current profile extrusions, but it is
**not credible for replacing the aircraft ledger** because the gate failures
below mean the placed CAD set is not a physical assembly.

## What v2 did establish

- `PartDefinition` is the common nominal source for DXF outline/cutouts,
  plywood extrusion and profile-volume mass rows; the manifest records profile
  hashes and part-instance mapping.
- Four 5×3-mm carbon longerons are present as stock solids at the preserved
  specified paths.
- The current hatch-rail placement gives a nominal 230×125-mm opening.
- The P60B solid is evaluated at -387.5, -384.78, -373.40, -370.0 and
  -332.5 mm, with a discrete withdrawal/cable envelope.  This is a CAD check,
  not a manufacturing release.
- Boom-saddle placeholders remain `NOT RELEASED` and are excluded from the
  flight-mass set and STEP assembly.

## Independent review blockers

The independent review found that the corrective model still has no verified
complementary tab/slot geometry: mates are largely metadata, several placements
either overlap or miss, and longerons/formers do not have validated locating
grooves.  It also found window/hardpoint conflicts, an unproven gear-cassette
load path, an unassembled nose tang/index box, and insufficient proof that
battery service clearances are contacts rather than excluded collisions.

Therefore all apparent `PROTOTYPE CUTTABLE` statuses are provisional model
labels only; a complete structural sheet must **not** be cut.  Required next
work is a placement-led feature model with complementary geometry, pairwise
collision/contact and edge-distance validation, then a new independent review.

## Aircraft-mass sensitivity

No wheels+FPV, skis+FPV, or wheels+FPV+45-g-HD replacement sensitivity is
published here.  Using the candidate mass/centroid would silently convert an
unaccepted CAD set into aircraft mass data.  After the mating and load-path
gates pass, calculate those three cases by replacing only the existing
398-g/(-1.6,0,0)-mm ledger item and report AUW, CG and battery X for 25% MAC;
no ballast assumption is permitted.

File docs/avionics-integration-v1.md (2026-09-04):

# LR1600 avionics, cooling and forward-controls integration v1

**Status:** preliminary packaging contract for the fuselage architecture.  It
uses the root-wing-leading-edge datum, with `+X` aft, `+Y` right and `+Z` up.
It is neither a wiring pinout nor an ArduPilot parameter file; exact FC board
revision and manufacturer documentation remain mandatory before wiring.

This document supersedes only the *physical-placement* assumptions for the
old tail-mounted Hitec servos.  The electrical direction, P60B pack study,
rail isolation and validation gates in
[electrical-rebaseline.md](electrical-rebaseline.md) remain applicable.

## Packaging stations and mass inputs

The following are centre-of-mass targets, in mm.  They are intentionally
specific enough for the next fuselage CAD study, while retaining a 10-mm
local adjustment allowance for brackets, hatches and cable exits.  No item is
credited as measured.

| Item | X | Y | Z | Mass (g) | Installation requirement |
|---|---:|---:|---:|---:|---|
| KST X08H V5 aileron servo, left/right | 135 | -450 / +450 | 0 | 8.0 each | Remains in the wing; direct short pushrod. |
| KST X08H V5 elevator servo | 110 | 0 | -15 | 8.0 | Removable central servo deck, output axis transverse. |
| KST X08H Plus V5 rudder servo, left | 110 | -32 | -15 | 9.6 | Independent output and independent pull--pull loop. |
| KST X08H Plus V5 rudder servo, right | 110 | +32 | -15 | 9.6 | Independent output and independent pull--pull loop. |
| Flight controller, isolated assembly | 125 | 0 | +15 | 30.0 | On rigid local shelf with controlled soft isolation; not on the gear plate. |
| Airspeed sensor | 150 | 0 | +15 | 4.0 | Same removable electronics shelf; pressure ports face aft/up and tubing is strain-relieved. |
| ELRS receiver | 95 | +48 | +20 | 4.6 | Serviceable side shelf; two antenna elements exit at 90 degrees. |
| SiK telemetry radio | 165 | -48 | +20 | 23.5 | Separate port-side antenna exit; regional band remains a procurement gate. |
| GNSS/compass | -105 | 0 | +95 | 9.0 | Non-ferrous upper mast or removable upper-shell pad. |
| FPV camera | -215 | 0 | +5 | 5.0 | Recessed nose cassette behind sacrificial bumper/window. |
| Optional Full-HD camera + isolated mount | -175 | 0 | +8 | 25--60 | Separate removable nose cassette; use its weighed mass in the CG ledger. |
| VTX | 250 | -48 | +20 | 8.7 | Port aft-side ventilated cassette; direct-bus filtered branch. |
| ESC (Skywalker 60A V2 envelope) | 285 | +42 | +5 | 68.0 | Starboard aft-side cooling duct, with short motor phase leads. |
| Servo DC/DC | 210 | +35 | 0 | 19.0 | Accessible power shelf; dedicated 6-V return trunk. |
| Logic 5-V DC/DC | 185 | +35 | 0 | 15.0 design estimate | Same shelf but separate clean output/return from servo rail. |
| Fuse, anti-spark/main disconnect and current sensor | 220 | 0 | 0 | 22.0 design estimate | Directly accessible after hatch opening; no discharge-path BMS. |

The five selected servos total **43.2 g** at `Xcg = 119.3 mm`, `Ycg = 0`,
`Zcg = -9.4 mm`.  This replaces the old 121.6-g Hitec five-servo set and its
tail locations; the old components/locations must not remain in any mass
ledger.

The first P60B pack must be entered as its weighed complete value.  The active
fuselage-prototype packaging contract is **503 g** and **155 x 75 x 28 mm**;
this overrides the smaller historical cell-block comparison envelopes in
`electrical-rebaseline.md`, which are not valid tray/removal geometry.  Its
rail position is deliberately owned by the CG closure, not by the avionics
layout.  Reserve a protected cable exit at the aft, lower-right corner of the
moving tray so that all pack positions leave at least 20 mm to the tray/hatch
edge and cannot pull on the connector.

## Forward-tail actuation

All three tail servos sit on a removable 2-mm birch-plywood servo deck carried
between structural fuselage frames; the deck itself is secondary and the
frames/longerons are primary.  Elevator and rudder outputs remain separate in
both mechanics and FC output assignment.  A removed hatch must expose servo
horn screws, output connectors, tensioners and the first guide without
removing the wing or battery.

| Route | Preliminary architecture | Length / supports | Mass allocation and mass centroid |
|---|---|---|---|
| Elevator | 3.0 x 1.0-mm carbon tube, M2 threaded end fittings, horn ball links; no flexible Bowden as the primary compression member. | Nominal centreline length 610 mm from `X=110` to tail; guide at <=150-mm unsupported spacing, with one axial-expansion/slip allowance at the aft guide. | 12 g at `X=415 mm`, including tube, end fittings, guides and horn hardware. |
| Left rudder | Own 0.45-mm 7x7 stainless closed-loop pull--pull cable, PTFE-lined fuselage transition and non-compressive boom guide clips. | About 720-mm one-way route (servo to boom transition then fin), so 1.44 m cable per rudder; guides <=150 mm, bend radius >=25 mm; tensioner at accessible tail horn. | 8 g at `X=414 mm`, including cable, liners, tensioner, exits and horn hardware. |
| Right rudder | Identical but physically independent route. | Same as left; no cross-coupling or shared bellcrank. | 8 g at `X=414 mm`. |

Thus the **forward-tail mechanical linkage allocation is 28 g at `X=414.4
mm`**.  Aileron pushrods, horns and wing-local installation are a separate
**12 g at `X=135 mm`** allocation.  The complete five-surface mechanical
linkage allocation is consequently **40 g at `X=330.6 mm`**.  Servo extension
leads, receiver leads and connectors belong to the wiring allocation, not to
these figures; reserve **10 g at `X=185 mm`** for control-specific leads only
if the master wiring item has not already absorbed them.

The 3-mm tube has an approximate pinned-column Euler load of 68 N at a 200-mm
free length (using 70-GPa carbon axial modulus), but only about 30--40 N of
control compression should be credited until the actual tube, guides and horn
geometry are tested.  The <=150-mm elevator guide pitch provides a sensible
preliminary margin.  Guides must locate laterally without crushing the tube;
test for no perceptible lost motion after thermal cycling, water/dust exposure
and 1000 full-control cycles.  Cable pull--pull is selected over a long
rudder-pushrod because it remains in tension, is tolerant of the boom route,
and has externally inspectable/tensionable failure points.  Its tension and
friction must be checked at both summer and winter temperatures.

## Electrical segregation and harness contract

Functional topology is:

```text
P60B pack -> fuse -> anti-spark/main disconnect -> current sensor -> ESC -> motor
                 |-> 6-V servo DC/DC -> five servos
                 |-> isolated clean 5-V DC/DC -> FC, GNSS, RX, telemetry, airspeed
                 `-> filtered direct-6S video branch -> FPV camera, VTX
```

- Battery-to-ESC positive and negative must be paired/twisted from tray exit
  to ESC, with no separately wandering return. The reserved route is about
  **674 mm one-way**. It therefore uses **4.0-mm2 silicone copper** and a
  voltage-qualified **680--1000-uF low-ESR capacitor at the ESC input**;
  final capacitance follows the selected ESC manual and a bench ripple test.
  With 4.3 mOhm/m representative copper resistance, the 1.348-m loop screens
  at 5.8 mOhm: about 0.20 V / 7.1 W at 35 A and 0.26 V / 11.8 W at 45 A.
  Measure installed resistance, connector temperature and ripple; do not
  infer a continuous-current approval from this screen.
- Keep motor phase wires <=120 mm from ESC to motor where packaging permits;
  twist the three phases.  Keep both phase and battery-current loops out of
  the GNSS mast, receiver antenna and video-signal routes.
- Run the clean 5-V output and I2C/UART loom on the upper centre/port chase;
  run servo 6-V and PWM as a paired trunk on the centre-lower chase.  The FC
  is the signal reference point: servo return current must return to the 6-V
  regulator, not through the FC's 5-V ground trace.
- Use locking connectors, chafe sleeves where a harness crosses a former, and
  a service loop only in low-current signal leads.  No high-current lead or
  antenna may be able to enter the propeller disk after a latch or tie fails.

Required geometric keep-outs, to be verified by powered testing rather than
treated as a guarantee:

| Sensitive item | Required preliminary keep-out |
|---|---|
| GNSS/compass at `(-105, 0, +95)` | At least 100 mm from motor, ESC, power leads/current sensor, VTX and ferrous landing-gear/motor/boom hardware; keep its mast and screws non-ferrous. |
| ELRS diversity antenna elements | Two 65-mm active elements at 90 degrees, with >=80 mm from VTX antenna and >=50 mm from high-current or motor phase wires.  Keep both outside carbon shielding where possible. |
| VTX antenna | Port aft-side exit, clear of propeller disk and >=100 mm from ELRS active elements; use 400 mW or less until the installed legal/RF/thermal check passes. |
| Airspeed tubing | One continuous supported run from probe to sensor; no radius <20 mm, no pinch under hatch, and no low-point water trap.  Leak-test after every wing/fuselage service event. |

Neither the H743-WING V3 PWM mapping nor the UART/I2C labels in legacy
documents are a permission to wire by assumption.  Before wiring, capture
the exact board revision/manual, then make a pin/resource record for the five
PWM outputs, CRSF, GNSS, telemetry, airspeed, current/voltage sensing,
battery monitor scaling, and all RC/GPS/airspeed/low-energy failsafe actions.

## Deliberate cooling architecture

The proposed openings are side-mounted above the wheel-spray and grass line;
they are not belly scoops.  Each has an internal 45-degree water/drip baffle
and 1.5--2-mm removable plastic mesh only where tests show that mesh pressure
loss does not compromise component temperatures.

| Circuit | Inlet | Outlet | Requirement |
|---|---|---|---|
| ESC / motor | Starboard side at `X=235..263`, `Z=+12..+32`; clear area >=330 mm2. | Starboard/aft at `X=315..345`, `Z=+18..+45`; clear area >=450 mm2. | A sealed local duct forces flow over the ESC heat spreader and then vents beside, not into, the motor mount.  Motor receives external propwash; its mount remains open for inspection. |
| VTX / video | Port side at `X=205..225`, `Z=+20..+35`; clear area >=180 mm2. | Port/aft at `X=270..295`, `Z=+22..+45`; clear area >=250 mm2. | Keep VTX in a removable metal-free cassette, thermally coupled to a small external plate if needed. |
| Battery / regulator | High, baffled forward-side inlet at `X=-445..-415`, clear area >=220 mm2. | Upper-side outlet immediately aft of tray at `X=-245..-225`, clear area >=300 mm2. | Flow crosses the protected pack/tray without direct dust blast. Do not use the battery bay as the ESC exhaust path. |

The outlet areas exceed inlet areas to tolerate duct and mesh losses.  Exact
temperatures, not opening area alone, decide acceptance: record ESC, motor,
pack, VTX and regulator temperatures at installed cruise, climb and short
adverse-power points.  A direct grass/water path to the battery, disconnect,
FC or VTX is unacceptable.

## Service and validation gates

The top hatch should expose battery latch/disconnect, fuse, both regulators,
FC, airspeed sensor, forward servos and their linkage exits.  A separate aft
side hatch exposes ESC/VTX and their ducts.  GNSS mast, camera cassette,
receiver/telemetry antenna bases and motor mount are individually removable;
routine service must not disturb FC orientation or battery rail indexing.

Before production fuselage CAD or flight release, pass all of the following:

1. Weigh all components and their brackets/lead extensions; replace the
   estimates above in the unified ledger and recompute all battery/CG cases.
2. Servo-load the actual elevator and each rudder linkage at 6 V, including
   hot/cold/dust/wet routing.  Demonstrate no binding, no visible backlash,
   rail >=5.7 V at the furthest servo, no regulator limiting and no FC reset.
3. Bench-map the installed motor/13x10 propeller, measured power leads,
   input capacitor and ducting. Confirm the Skywalker 60A V2 installation
   stays inside its documented current/thermal limits with margin; do not
   substitute a lower-current ESC without a new thermal and ripple assessment.
4. Conduct powered compass interference, GNSS lock, ELRS range, telemetry
   and video coexistence checks with motor running, VTX powered, all landing
   gear installed and servos exercised.  Change the placement or select a
   compass-less GNSS variant if the survey fails.
5. Leak-test the airspeed route and bench-validate documented ArduPilot
   response to loss of RC, GPS, airspeed and usable battery energy before any
   maiden parameter changes.

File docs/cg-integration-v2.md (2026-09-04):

# LR1600 CG integration v2

This is a reproducible **design estimate** for the 2,600-g integration case,
not a weighed aircraft or a flight-CG release.  The single editable mass
ledger is [`config/hardware.yaml`](../config/hardware.yaml); the complete,
machine-readable derived ledger and all arithmetic are in
[`analysis/mass/summary.json`](../analysis/mass/summary.json), produced by
[`scripts/cg_integration.py`](../scripts/cg_integration.py).  No mass in this
document is a second source.

## P60B placement and baseline closure

The P60B branch is a 503-g complete 6S1P **packaging estimate** with a
155 x 75 x 28-mm envelope.  The prototype pack rail has 55-mm useful travel:

| Setting | Battery centre X | Baseline wheels CG X | CG % MAC |
|---|---:|---:|---:|
| Forward | -387.5 | 65.72 | 23.76% |
| Nominal rail reference | -370.0 | 69.19 | 25.30% |
| Aft | -332.5 | 76.64 | 28.59% |

The exact central-ledger pack centres required are -384.78, -373.40,
-362.03 and -339.27 mm for 24, 25, 26 and 28% MAC respectively. Therefore
24% and 25% are reachable without ballast: their centres lie 2.72 mm and
14.10 mm aft of the new forward rail limit. The physical pack needs X=-465 at
the forward index; the X=-500 nose and top hatch are deliberate consequences
of that calculation, not an arbitrary long nose. A real pack/dummy must prove
the removal path, cable bend radius, index stops and 44.4-N retention proof
before production release.

## Unified central mass result

The central summer estimate is **2533.5 g**: 66.5 g below the 2,600-g
integration design case.  Its bounded low/central/high mass screen is
**2260.6 / 2533.5 / 2846.4 g**. The low/high screen varies only entries with
explicit component-local ranges; fixed datasheet entries are held central. It
is not an acceptable release mass and shows why actual assemblies and their
moments must be weighed.

Included central groups are wing plus joiner 591.25 g, boom pair 120.28 g,
empennage 115 g, 13x10 motor/prop/ESC/mount 291 g, P60B pack 503 g, five
servos 43.2 g, mechanical linkages 40 g, avionics/regulators/sensor 140.8 g,
wiring 95 g (including the long 4-mm2 power pair/capacitor allowance),
fuselage structural group 398 g, and complete fixed-nose wheel gear 196 g.
The JSON lists every individual ledger component and its X/Y/Z point.

The 398-g fuselage group includes its structural hardpoints; they are not
added again to landing gear.  Wheel gear is replaced, not supplemented, by
the ski module.  The optional camera is likewise excluded from baseline.

## Seasonal and recording configurations

| Configuration | Mass at nominal rail | 25% target battery X | Result at current nominal / forward / aft rail |
|---|---:|---:|---|
| Wheels, FPV | 2533.5 g | -373.40 | 25.30 / 23.76 / 28.59% MAC |
| Skis, FPV | 2569.5 g | -365.57 | 24.62 / 23.10 / 27.87% MAC |
| Wheels, FPV + 45-g HD central payload | 2578.5 g | -351.62 | 23.41 / 21.90 / 26.65% MAC |

For wheels, move the pack forward about 3.4 mm from the nominal rail reference
to make 25%; for skis, move it aft about 4.4 mm. For the 45-g recording case,
move it aft about 18.4 mm. All 25% cases close without ballast. The current
rail covers exact 24% and 25% in all three stated configurations. It covers
the full 24--28% range for wheels; skis miss exact 28% by 1.56 mm aft and the
HD case misses it by 15.63 mm aft. These are explicitly reported limitations,
not reasons to put electronics in the tail. The HD study range is 25--60 g;
its actual mount/camera mass must be entered before any flight release.

## Handling implication

At the exact 25% case, battery X=-373.4048 mm and CG X=68.5185 mm put the pack
441.92 mm (about 442 mm) ahead of aircraft CG. Its point-mass pitch-inertia
contribution is 0.0982 kg m2 (0.0992 kg m2 including the 155-mm pack's
longitudinal extent). It is an intentional penalty of
no-ballast closure.  The countermeasure is mass concentration: FC and the
three tail servos stay close to the wing/CG region; no heavy tail electronics
are accepted for mechanical convenience.

## Release blockers

- Weigh pack, wing, booms, tail, fuselage, gear and actual accessories, then
  recompute this ledger and physically measure all-up CG.
- Prove the pack box, long primary nose path, wing/boom/motor interfaces and
  gear/skis hardpoints before cutting production parts.
- Close motor/13x10 propulsion, cooling, vibration, EMI and servo/linkage
  evidence.  The 2,600-g value is technically coherent as an integration
  case, but remains conditional rather than a final flight MTOW.

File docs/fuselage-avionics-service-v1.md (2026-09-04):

# LR1600 fuselage prototype v1: avionics and service contract

**Status:** prototype-integration requirement. This document assigns
installation requirements to the fuselage CAD; it does not select an FC
revision, a connector family, an ArduPilot pinout, or flight parameters. All
coordinates use the root-wing-leading-edge datum, in mm, with `+X` aft,
`+Y` right and `+Z` up. Primary CAD must retain the primary/secondary
classification stated here: an equipment tray, printed guide, camera cassette,
duct, mesh and hatch lid are **SECONDARY STRUCTURE**. They must not close a
wing, boom, motor, battery or landing-gear load path.

The physical component-envelope source is `config/aircraft.yaml`; the
commercial hardware/mass ledger is `config/hardware.yaml`. This document must
not become a second editable coordinate or mass source. The P60B prototype
pack contract is 503 g and 155 x 75 x 28 mm. Historical 70.2 x 64.7 x
43.1-mm cell-block figures are comparison-study values, not valid battery-tray
or removal geometry.

## Required removable modules and service faces

| Module | CAD provision | Service acceptance for prototype |
|---|---|---|
| P60B tray and dummy | Primary tray, stops, rails and restraint interfaces; dummy is **JIG / TOOLING**. | With wing installed, make the system safe, disconnect, release retention and lift the dummy vertically without contact with an FC, servo horn, wiring or a structural member. The CAD check shall retain the whole `155 x 75 x 28` pack swept volume plus the actual cable sweep—not a centreline only. |
| Central electronics shelf | Removable **SECONDARY STRUCTURE** shelf between primary frames; four-screw or equivalent repeatable mount. | FC, airspeed sensor and output connectors can be removed without wing removal and without changing the FC orientation datum. FC is not mounted on a gear plate or a flexible shell. |
| Tail servo deck | 2-mm-birch removable **SECONDARY STRUCTURE** deck carried by primary frames. | Elevator and both rudder servos at the typed `X=110` stations have screw, horn, connector and first-guide access from the upper service opening. Replacing one servo cannot disturb either other rudder loop. |
| ESC / VTX cassettes | Separate ventilated **SECONDARY STRUCTURE** side cassettes. | ESC or VTX is removable from its own side opening; the operation does not require removing the battery rail, FC shelf or motor base. |
| FPV and HD cassettes | Break-away printed or light-composite **FAIRING / NON-STRUCTURAL** modules. | FPV camera at its typed nose zone is replaceable from the front/bottom service face. The optional HD cassette has a separate real attachment and must not share an FPV retention screw or become an impact load path. |
| GNSS, antennas and Pitot | Non-ferrous upper pad/mast plus replaceable guides. | GNSS pad, receiver/telemetry antenna bases and Pitot tube can be inspected/replaced without opening a high-current cable clamp. |

The battery proof must use the real 503-g inert dummy, with its intended
connector and lead surrogate. A hatch projection that fits the bare block is
not a removal pass. The check has three positions: rail forward limit, exact
25%-MAC index and rail aft limit. Record the rail positions from the typed
prototype source after its requested forward extension is implemented.

### Battery cable and hatch clearance resolution

Prototype v1 uses a **230 x 125-mm clear opening**. A centred 75-mm pack then
has 25 mm lateral projected clearance at each side, satisfying the 20-mm
cable/tray-edge allowance before rail or rim intrusions. The CAD removal
solid must still prove that this full clearance remains at the actual cable
exit; do not hide a local reduction in a printed bezel, foam shell or harness
loop. The old 230 x 110-mm reservation is superseded and must not be cited for
this prototype.

## Harness corridors and physical segregation

These corridors are allocation volumes, not primary structure and not an
authority to infer FC pins. CAD shall model every crossing through plywood as
a rounded, grommet-capable hole or an accessible edge clip; no harness may be
captured behind a bonded primary web.

| Corridor | Location / direction | Carries | Required separation and retention |
|---|---|---|---|
| High current | Starboard, lower side; pack exit to disconnect/current sensor/ESC, then motor. | Twisted paired battery leads; short twisted three-phase motor leads. | Pair positive/negative from tray to ESC; phase leads target <=120 mm. Keep outside GNSS/compass, ELRS active elements, video signal and servo signal corridors. Tie at both sides of each structural penetration; no free wire can enter the propeller disk. |
| Clean signal | Upper centre/port chase. | 5-V logic, GNSS, CRSF, telemetry, I2C/UART and Pitot-sensor lead. | No shared clamp or return with propulsion or servo-current wiring. Use service loops only on low-current leads. |
| Controls | Centre-lower chase, physically independent from both rudder cable paths. | 6-V/PWM trunk and elevator-servo lead. | Paired power/return to each load; servo return returns to the 6-V regulator, not through the FC logic ground trace. |
| RF/video | Port side, with individual antenna exits. | Filtered direct-bus video, camera lead, VTX coax, receiver and telemetry antenna supports. | VTX antenna >=100 mm from ELRS active elements; ELRS active elements >=50 mm from high-current/phase wiring and outside carbon shielding where practical. |
| Pneumatic | Upper protected centre run. | One continuous Pitot tube to the airspeed sensor. | Bend radius >=20 mm; no hatch pinch, no low-point water trap and no shared hole with high-current wiring. |

GNSS/compass remains at the typed upper-forward zone and requires at least
100 mm from motor, ESC, high-current loop/current sensor, VTX and ferrous
gear/motor/boom hardware. The non-ferrous mast and its fasteners are part of
that requirement. A powered installed compass survey, not CAD distance alone,
is the acceptance evidence.

## Cooling and contamination control

The prototype reserves three independent, baffled flow paths. Inlets are side
or upper-side openings above the wheel spray/grass line; they are not belly
scoops. Each removable 1.5--2-mm mesh screen and 45-degree drip baffle is
**SECONDARY STRUCTURE** and must be removable for cleaning.

| Circuit | Inlet / outlet reservation | CAD acceptance |
|---|---|---|
| ESC/motor | Starboard inlet `X=235..263`, `Z=+12..+32`, free area >=330 mm2; outlet `X=315..345`, `Z=+18..+45`, >=450 mm2. | Local duct forces air over the ESC heat spreader then out beside the motor interface. Motor is externally propwash-cooled. Battery bay is not the ESC exhaust. |
| VTX/video | Port inlet `X=205..225`, `Z=+20..+35`, >=180 mm2; outlet `X=270..295`, `Z=+22..+45`, >=250 mm2. | Removable metal-free VTX cassette; no sealed foam pocket. |
| Battery/regulators | High baffled forward-side inlet `X=-445..-415`, >=220 mm2; upper-side outlet aft of tray `X=-245..-225`, >=300 mm2. | Flow crosses the protected tray but has no direct dirt/water path to pack, disconnect, FC or regulator. |

Outlet free area is at least inlet free area after baffles/mesh. The final
acceptance is logged temperatures of ESC, motor, pack, VTX and regulators at
installed cruise, climb and the short adverse-power point—not the nominal
opening area.

## Controls, RF and camera details

The elevator uses the 3.0 x 1.0-mm CFRP pushrod with guides at no more than
150-mm unsupported spacing. Each guide laterally locates without clamping the
rod axially; the aft guide supplies the thermal/assembly slip allowance.
Rudder-left and rudder-right remain independent 0.45-mm closed pull--pull
loops: individual PTFE transitions, exit guides, tail tensioners and no
crossing/shared bellcrank. Minimum bend radius is 25 mm. The service opening
must expose both tensioners and each first guide, and a failed/detached loop
must not be able to foul the other loop.

The FPV camera is a protected, recessed, replaceable nose cassette. A
separate HD cassette in its reserved forward zone is optional payload only;
its 25--60-g actual installed mass must be entered in the ledger before
flight. Neither camera housing, lens window nor printed mount supports the
nose gear, skid, battery box or outer shell.

## Prototype test record required before flight configuration

1. Dummy-pack service trial and six-direction 44.4-N battery-retention proof:
   forward/aft stops, vertical restraint and lateral restraint each sustain
   the full proof load independently. Recheck all three removal positions.
2. Five-servo 6-V transient/thermal test through actual linkages. Require
   >=5.7 V at the furthest servo, no regulator limiting and no FC reset.
3. Leak-test Pitot tubing after every fuselage/wing service event; operate it
   through the full hatch/tray motion and inspect for a kink or water trap.
4. Powered compass, GNSS, ELRS, telemetry and video coexistence/range survey
   with motor running, VTX powered, servos exercised and landing gear fitted.
5. Bench-test ESC/motor/13x10 installation with the actual long power pair,
   capacitor, duct and cable clamps. Inspect ripple, heat, connector rise and
   wiring motion; validate temperatures rather than treating routing as proof.
6. Before any ArduPilot change, make a board-revision-specific pin/resource
   and failsafe record: PWM outputs, CRSF, GNSS, telemetry, airspeed,
   battery-monitor scaling, RC loss, GPS loss, airspeed loss and low-energy
   recovery behaviour. This prototype provides no approval to infer pinout or
   modify a physical flight controller.

Passing a CAD collision check means only that the reserved volumes do not
overlap. The physical tests above, actual hardware mass/CG measurement and
the independent prototype review remain release gates.

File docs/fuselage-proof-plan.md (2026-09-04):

# LR1600 Fuselage Prototype v1 — proof articles and gates

**Status:** required physical proof plan; no test result is implied.  The
2,600-g integration design case is the source-of-truth mass case.  This plan
does not validate wing structure, unselected boom tubing, the selected motor,
or a full aircraft.  Use a guarded fixture, calibrated/known load, a catch
where falling mass is possible, photos and the [test record sheet](test-record-sheet.md).

## General method

Use the actual CAD article, actual birch/carbon/fasteners/adhesive and actual
assembly preparation.  Test in 25/50/75/100/proof increments with a 60-s dwell
at each unless a fixture-specific instruction is safer.  Measure initial and
residual deflection/alignment after unloading.  Stop immediately for crack,
split, audible fibre failure, adhesive-line opening, permanent set, hole
ovality, bolt/pin movement, clamp slip, delamination or a change in indexed
heading.  Shields are mandatory around carbon/GFRP, moving levers and hanging
weights; no person stands in the load line.

Pass means the full stated proof load is held with no damage, no permanent set,
no slip and no alignment loss beyond drawing tolerance.  Passing is a
prototype gate, not an ultimate strength allowable or production approval.

## Required representative articles

| ID / article | Representative content | Applied proof / method | Required observations and likely first failure |
| --- | --- | --- | --- |
| `FG-MAIN-ROOT-01` | X=+65…+200 `FUS-GEAR-DOUBLER-*`, `FUS-GEAR-SPREADER-*` and `FUS-GEAR-CLAMP-LAND` cassette; 2-mm closure webs, lower longeron segments, actual spreader/bolts and a GFRP leg root. | **121 N vertical** on one main; separate **35 N lateral** and **35 N longitudinal** at the wheel/leg reaction line. Apply through a rounded wheel/axle fixture, not directly to one plywood edge. | Leg-root delamination/yield, birch bearing/net-section split, bolt slip, adhesive peel, longeron disturbance and residual gear alignment. |
| `FG-NOSE-INDEX-01` | X=-285 lower-keel box, `FUS-NOSE-INDEX-BLOCK`, two `FUS-NOSE-INDEX-DOUBLER` parts, actual strut tang/capture hardware and an accurate fork/strut dummy or real part. | **60 N vertical**, then **35 N lateral** and **35 N longitudinal** with the tang captured in its 12-mm key. | Key-face crush, plywood split, capture-bolt migration, yaw slip and residual straight-ahead heading. Clamp friction is not credited. |
| `FG-BATTERY-RET-01` | Full rail/cradle, `FUS-BAT-FWD-STOP`, `FUS-BAT-AFT-STOP`, both `FUS-BAT-STRAP-ANCHOR-*` pairs, hatch opening and inert 503-g dummy. | **44.4 N** in +X, -X, +Y, -Y, +Z and -Z, one direction at a time. Cycle pack removal/reinstallation after proof. | Stop crush/splitting, rail pull-out, strap-anchor tear-out, buckle/fastener release, hatch interference or connector misuse. Each independent stop/strap path must demonstrate its full assigned reaction. |
| `FG-BOOM-CLAMP-01` | One `B285`/`B365` clamp frame segment, the actual tube, actual compliant liner, clamp hardware and a representative boom stub. | Establish safe tightening torque first.  Apply axial slip, transverse and torsion screens derived from the coupled boom load release analysis; repeat at least ten install/remove cycles. | Carbon local crush, liner creep, frame split, bolt bearing, clamp slip and lost angular index.  **No numerical boom structural approval exists until tube data/load case is closed.** |
| `FG-MOTOR-PLATE-01` | Fixed cross-member, `B365` support, actual removable plate/adapter, selected or accurate motor mass/CG and bolts/shear keys. | Current provisional screen: **15.1 N axial**, **1.26 N m torsion**, **0.64 N m inertia bending**.  Replace with selected-motor measured static thrust, 1.5x measured torque and 4-g inertia at actual offset before release. | Plate twist, bolt bearing, key slip, fastener loosening, carbon crush and prop-axis movement. |
| `FG-CARBON-BIRCH-01..03` | Actual 5 x 3 longeron stock bonded to laser-cut/prepared birch with the same overlap, adhesive and cure as fuselage. | Slow guarded lap/peel/shear comparison, three repeats.  Record maximum applied load and failure mode; do not derive a generic allowable. | Adhesive/carbon interface failure, plywood delamination or peel at a square termination.  Adhesive/carbon-interface failure fails the preparation gate. |
| `FG-TAB-SLOT-2/3` | The actual 2-mm and 3-mm material, representative tab/slot teeth and corner relief. | Laser-process calibration / repeated dry insertions, not a structural qualification. | Finished fit, tab damage, char, slot ovality and need for downstream kerf setting. |

The existing plywood bearing and carbon-to-birch coupons in
[material-testing.md](material-testing.md) remain prerequisites; these fuselage
articles add the real load path and assembly geometry they cannot represent.

## Full skeleton proof sequence

After the relevant representative articles pass, proof the dry structural
skeleton before light shell completion:

1. Install the instrumented/marked dummy battery, gear interfaces, boom/motor
   alignment fixtures and wing-side gauges.  Record initial X/Y/Z datums,
   diagonals, motor axis and indexed nose heading.
2. Carry out main and nose hardpoint proof as installed assemblies.  Use a
   fixture that follows the real reaction line and supports the fuselage at
   its intended wing-interface/datum locations; do not make the foam shell a
   reaction member.
3. Apply battery retention proof in all six directions; remove/reinstall the
   dummy through the hatch afterwards.  A retained battery that cannot be
   serviced is a failure of this prototype objective.
4. Fit the non-rotating 13-in prop disk and run the compression / 20-mm-rut /
   8-degree tail-low clearance check.  This validates geometry only; it is not
   a rotating-prop test.
5. Verify boom alignment under the current fixture.  Coupled wing/boom bending
   proof is a separate release gate and is not inferred from a static
   clamp-fit check.
6. Inspect every bond line, longeron, hardpoint, clamp, gear key and fastener;
   weigh the bare skeleton and each removable group.  Enter measured mass and
   station moments in the hardware ledger workflow, then recompute CG.

## Proof closure criteria and blockers

The prototype may proceed from cut parts to a dry structural assembly only
after tab/slot calibration and the battery removal sweep are demonstrated.  It
may receive the representative loaded interfaces after the associated articles
pass.  It is **not** production-ready until all of the following are closed:

- actual birch density/thickness, bearing/net-section and carbon-birch bond
  evidence;
- selected GFRP laminate thickness/lay-up, root holes and fatigue/impact
  behaviour;
- main root and fixed nose-index proof with residual alignment recorded;
- selected boom tube OD/wall/allowables, non-crushing liner torque and coupled
  wing/boom bending proof;
- selected motor/adapter measured thrust, torque, vibration and motor-plate
  proof;
- six-direction battery proof, repeated wing-on service removal and measured
  pack/structure mass and CG;
- physical prop-clearance, cooling/EMI and installed avionics service checks.

Until then, all fuselage flight hardware and full assembly remain
`NOT RELEASED`; only explicitly labelled plywood parts and jigs are
`PROTOTYPE CUTTABLE` / `TOOLING`.

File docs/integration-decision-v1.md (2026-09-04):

# LR1600 integration decision v1: forward battery bay

**Decision:** accept the extended forward fuselage and P60B rail as the
preliminary, reversible packaging baseline for the 2,600-g integration case,
subject to the structural and validation conditions below.  Use an external
nose limit of **X=-500 mm**, a 155 x 75 x 28-mm P60B study envelope, indexed
battery-CG travel **X=-387.5...-332.5 mm**, and nominal index **X=-370.0 mm**.
This is sufficient to proceed to a packaging/skeleton CAD study; it is not a
production-CAD freeze or flight release.  Wing geometry, wing structural
concept and the root-wing-LE datum are unchanged.

## Inputs and closure

The current unified central ledger uses a 503-g complete-pack estimate, a
398-g fuselage estimate with its revised centroid near X=-1.6 mm, and 196 g of
fixed-nose wheel gear. Solving the longitudinal first moment for the configured MAC
targets gives:

| Target | CG X, mm | Required battery CG X, mm | Rail-end margin, mm |
|---:|---:|---:|---:|
| 24% MAC | 66.26 | -384.78 | 2.72 from forward limit |
| 25% MAC | 68.52 | -373.40 | 14.10 / 40.90 |
| 26% MAC | 70.78 | -362.03 | 25.47 / 29.53 |
| 28% MAC | 75.30 | -339.27 | 6.77 from aft limit |

The prototype's deliberate 5-mm forward rail extension makes exact 24% and
25% MAC mathematically reachable without ballast; the wheels 24--28% range is
inside the rail. Before any production tray, repeat the solver with weighed
components and retain space in the skeleton for a deliberate rail/stop
decision; do not trade primary structure for extra travel.

The union of pack positions is X=-465...-255 mm. At the forward setting,
the X=-500 outer limit leaves 35 mm ahead of the estimated pack envelope for
a 3-mm tied stop, insulation and a sacrificial bumper/crush space.  This is a
preliminary packaging allowance, not an impact-qualified battery enclosure.
The 230 x 125-mm clear top opening is adequate as a geometric reservation at
both stops: move the pack to a chosen index, isolate and disconnect it, then
lift vertically. The aft pack end is X=-255 at the aft stop, leaving about
13 mm to the X=-242.5 hatch edge. Mock up the actual pack, connector bend
radius, straps, latch and hands/tool access before fixing hatch geometry.

## Structural resolution

The extended nose is coherent only as a primary battery-box cantilever, not as
skin-supported packaging.  The earlier statement that the four primary
longerons run only from X=-170 was incompatible with a forward stop near
X=-475.  The resolved skeleton extends the lower longerons and continuous side
sill/shear path from the forward battery stop region (no later than X=-475)
through the X=-55 wing-forward shear frame and central gear/wing box.  Route
the upper members around the hatch perimeter with closed end rings and local
diagonal shear webs; the removable hatch and foam/composite skin receive no
primary bending or torsion credit.  The forward and aft battery stops, both
20-mm straps and rail attachments must feed this same box in double shear.

For scale, the pack alone at the forward rail end produces about **29.6 N** at
the stated 6-g retention case.  Its bending contribution about the X=-55 frame
is about **9.9 N m operational** and **14.9 N m proof** at factor 1.5.  Nose
structure, FPV/optional camera and local landing/obstacle loads are additional;
these numbers are not the complete nose-box design load.  Coupon allowables
and a representative assembled-box proof are required before manufacture.

## Handling and service trade

At the 25%-MAC target, the pack centre is about 442 mm ahead of CG. A point
mass screen gives approximately **0.098 kg m2** battery pitch inertia about CG
(about 0.099 kg m2 including the pack's own 155-mm longitudinal extent). The
same pack at X=-330 would contribute about 0.080 kg m2, so the accepted CG
solution adds roughly **0.020 kg m2** from the battery alone.  This is a real
pitch-response and rough-landing penalty, but preferable to ballast or moving
servos/electronics to the tail.  Keep all other heavy equipment near CG and
make the nose bumper/lower skid replaceable.

Service access remains acceptable if the battery has a guarded disconnect
reachable before unlatching, positive indexed stops, two independent retained
straps, and no servo horn or high-current cable crossing the vertical removal
path.  A jammed or deformed forward stop must be replaceable without removing
the wing or opening the central gear box.
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

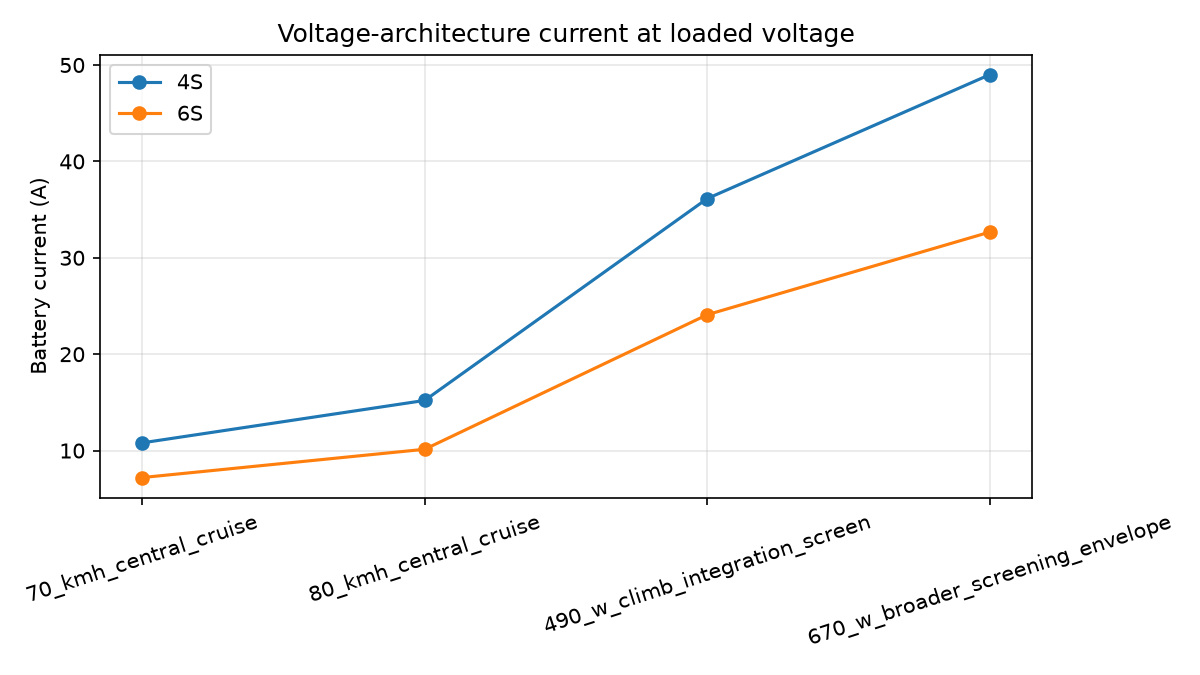
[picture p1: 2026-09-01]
analysis/powertrain/plots/current_vs_architecture.png

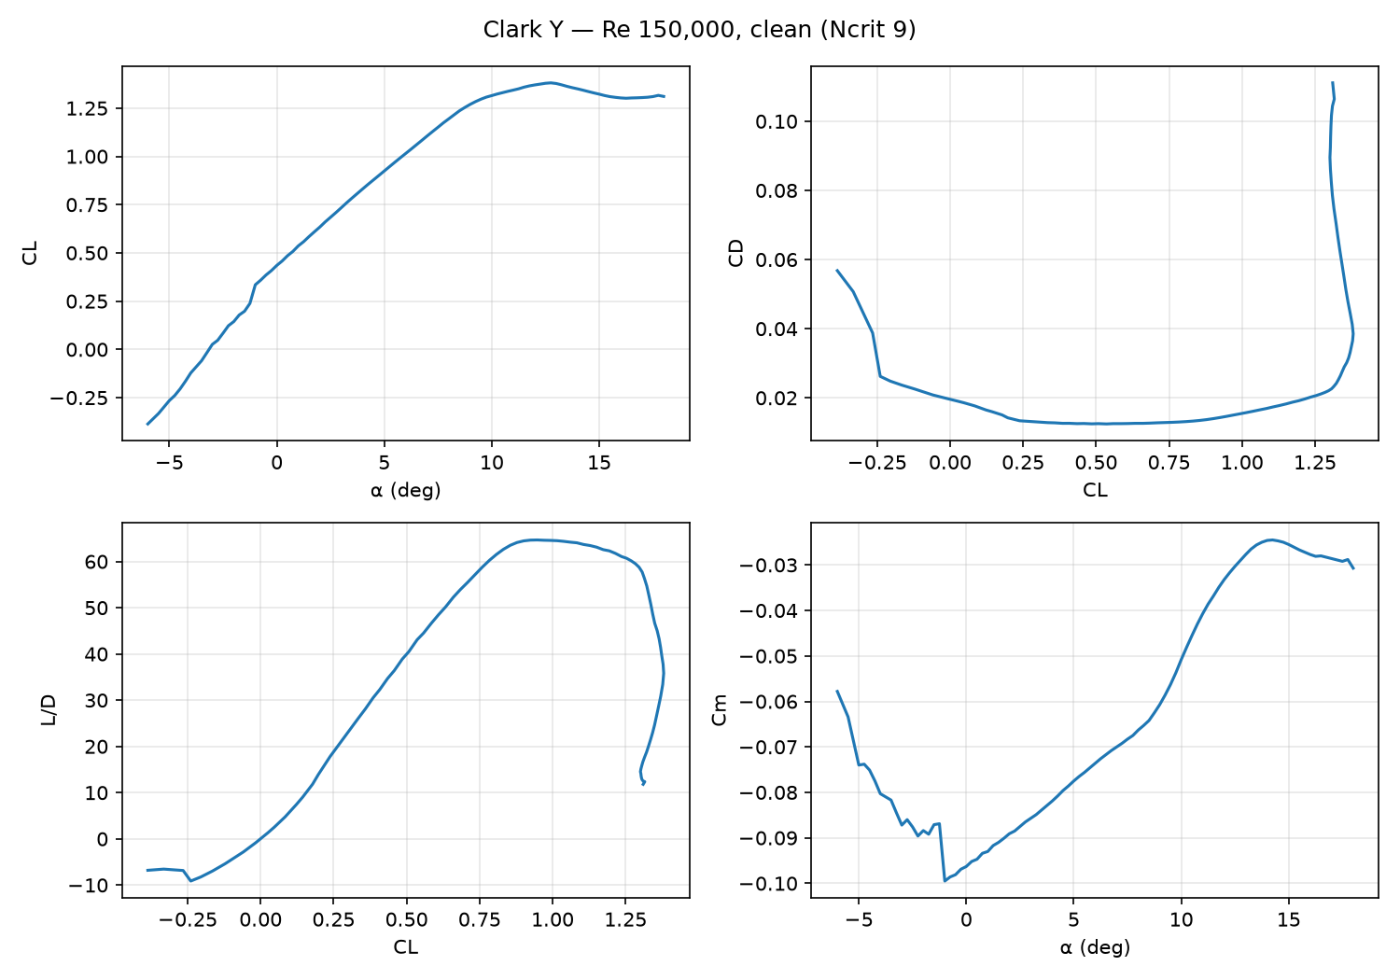
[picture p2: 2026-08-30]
analysis/aero/plots/clarky_re150000_clean.png

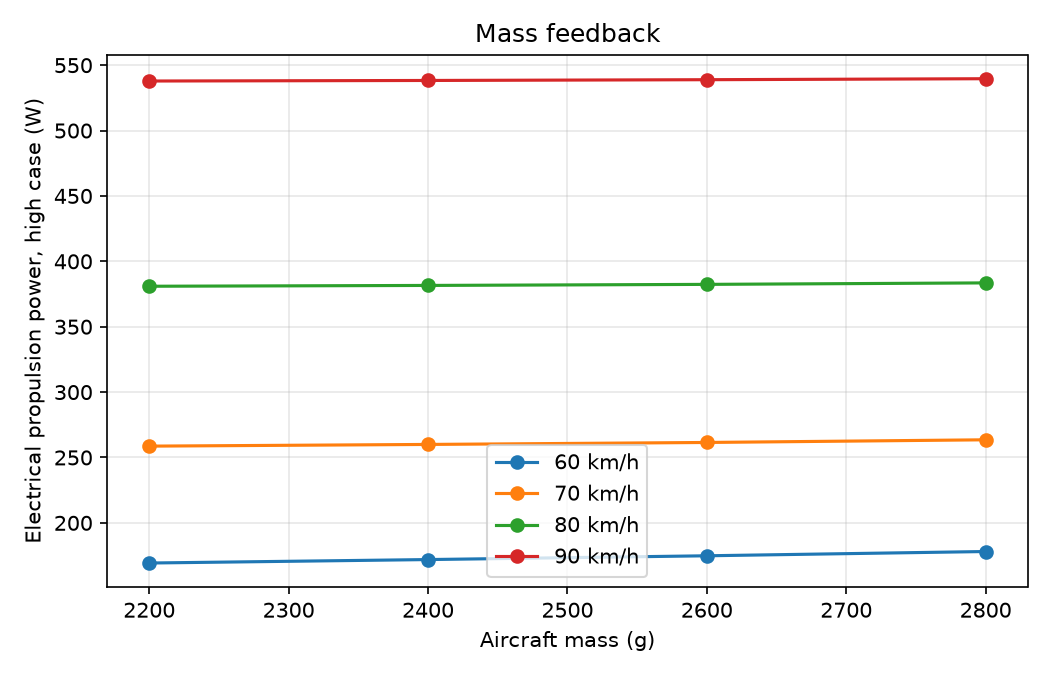
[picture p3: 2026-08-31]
analysis/propulsion/plots/power_vs_mass.png

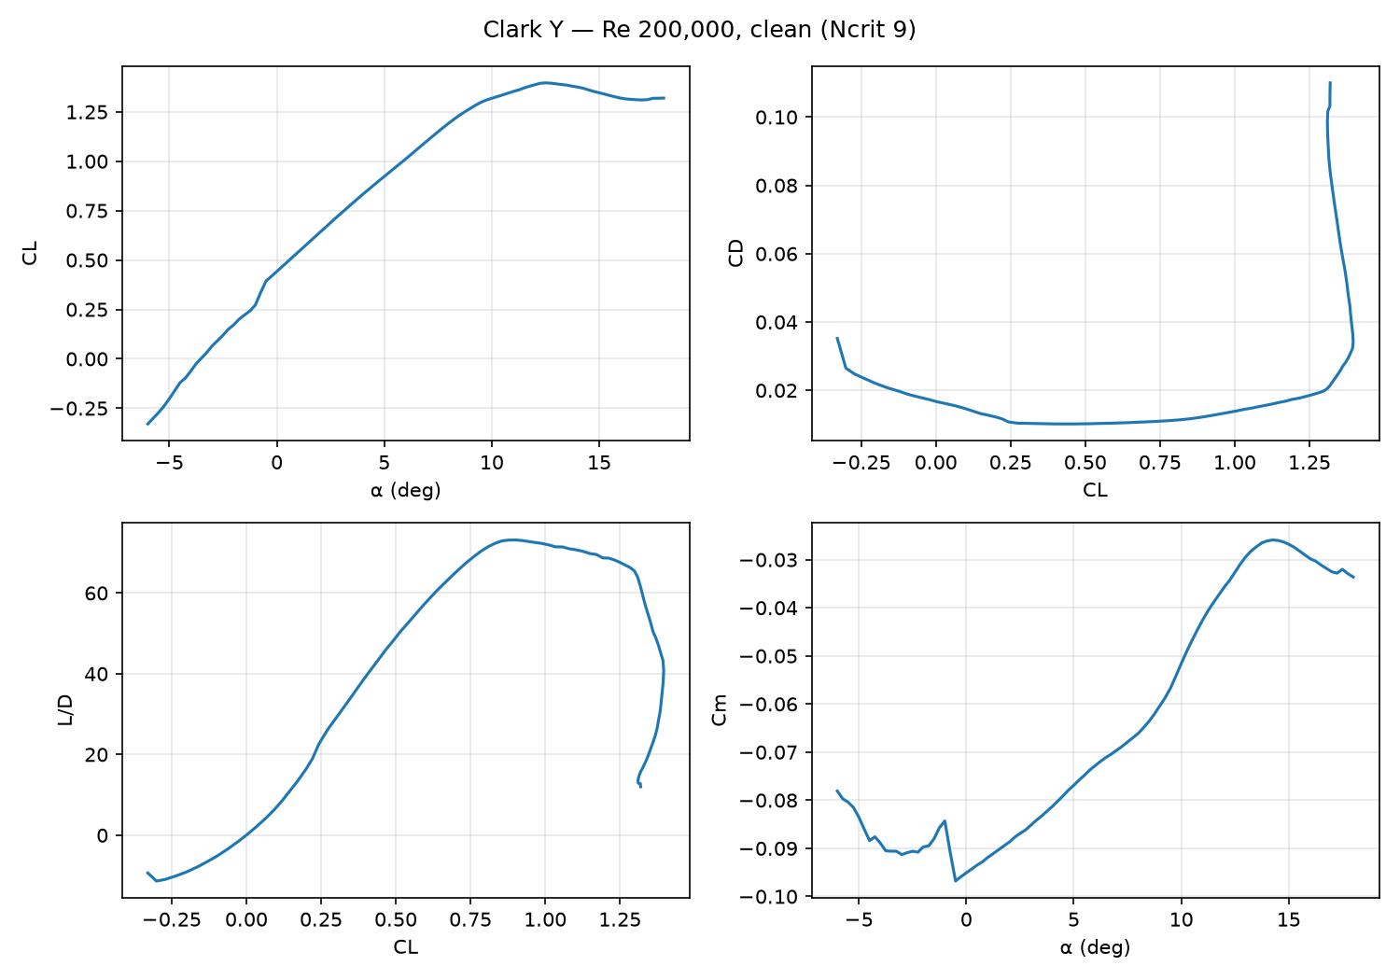
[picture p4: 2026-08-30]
analysis/aero/plots/clarky_re200000_clean.png

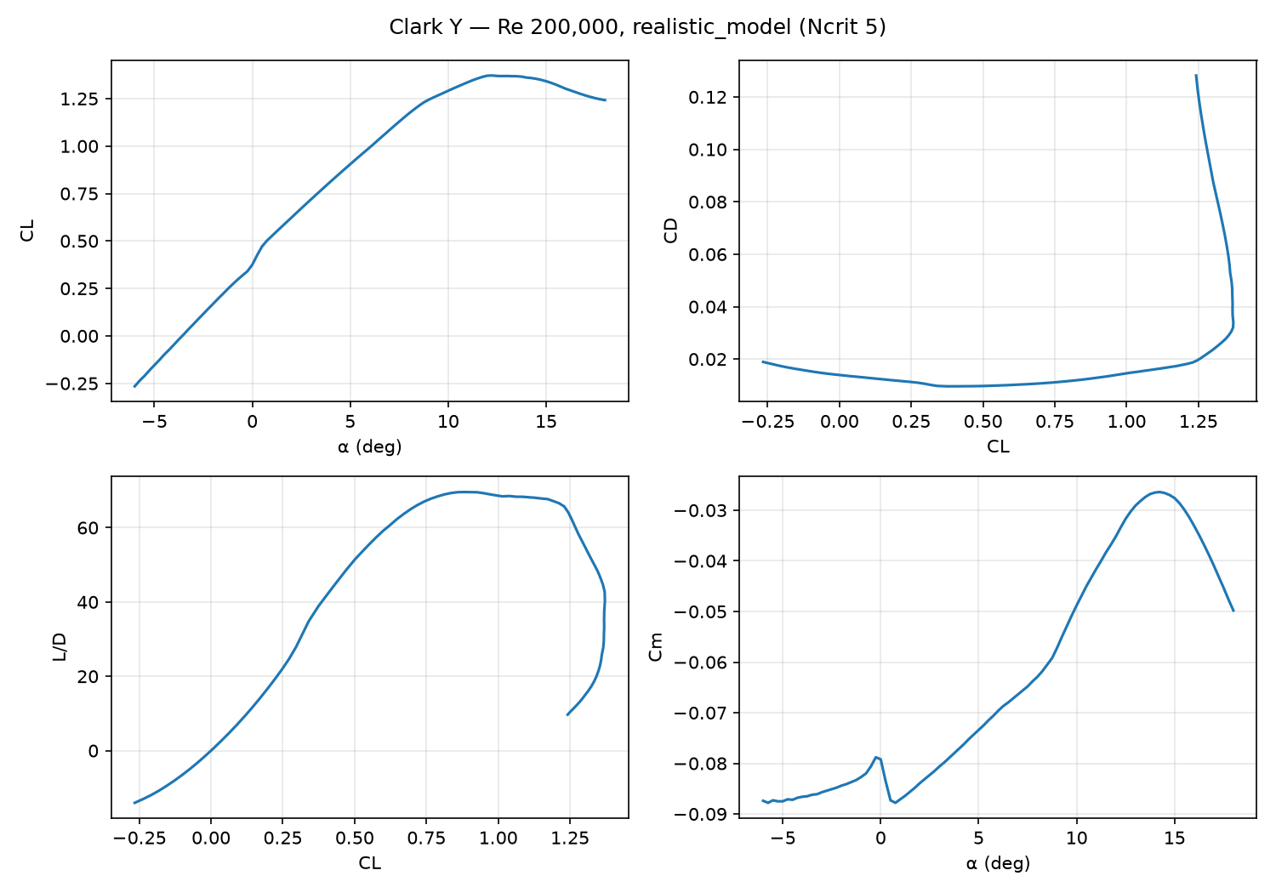
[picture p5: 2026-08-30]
analysis/aero/plots/clarky_re200000_realistic_model.png

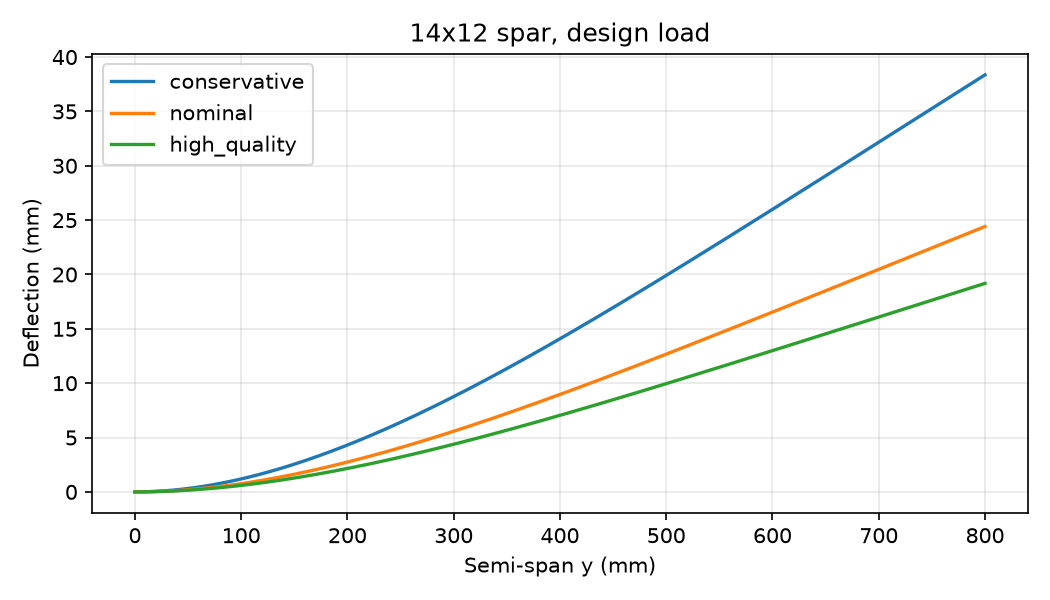
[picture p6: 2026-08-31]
analysis/structures/deflection_vs_span.png

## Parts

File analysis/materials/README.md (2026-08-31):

# LR1600 material measurements

`measurements.yaml` is an untracked, user-entered laboratory notebook in YAML.
Copy `measurements.example.yaml`, enter only observations actually made, then
run:

```bash
python3 scripts/analyze_material_measurements.py
python3 scripts/analyze_wing_structure.py --materials-results analysis/materials/results/summary.json
```

The first command writes derived values to `analysis/materials/results/summary.json`.
It never fills in a missing value from an engineering assumption.  Every result
has a `state`: `MEASURED`, `DATASHEET`, `ASSUMPTION`, `DERIVED`, or
`NOT_MEASURED`.  This workflow records measured geometry, mass and stiffness;
it does **not** create a tensile, compression, bearing or adhesive-strength
allowable from a home test.

`measurements.example.yaml` is intentionally empty but valid.  Keep raw
observations in `measurements.yaml`, photos under `analysis/materials/photos/`,
and do not edit a generated result by hand.

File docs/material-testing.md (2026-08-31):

# LR1600 material-validation workflow

This home-test programme reduces uncertainty in the preliminary wing concept in
[structures.md](structures.md). Aircraft geometry, target mass and load factor
remain only in `config/aircraft.yaml`, read by the typed config loader. No result
changes geometry or a strength allowable.

> **Poplar plywood 1.5 mm is not available and must not be used. Available
> poplar plywood thickness is 2.0 mm.**

## Start and data entry

Copy `analysis/materials/measurements.example.yaml` to ignored
`analysis/materials/measurements.yaml`; give every specimen an ID, enter raw
values, and keep photos in `analysis/materials/photos/`. Run
`./tools/cad-shell.sh scripts/analyze_material_measurements.py`. It writes
`analysis/materials/results/summary.json`; absent input stays `NOT_MEASURED`.
`MEASURED` means an observation, `DATASHEET` a supplier statement,
`ASSUMPTION` a separate screen and `DERIVED` a calculation from observations.

Use a 0.1-g-or-finer scale and a 0.1-mm-or-better caliper (0.01-mm micrometer
is preferred for plywood). If a 100 x 100 foam coupon weighs below 2 g on a
0.1-g scale, use 200 x 200 coupons or a stack. Record instrument resolution,
ambient temperature and photo filename.

The importer validates `metadata.format_version = 1`,
`metadata.data_variant = home-test-v1`, every top-level domain and rejects unknown fields,
negative loads/masses and impossible dimensions. It writes SHA-256 provenance
for the raw measurement YAML and the typed aircraft YAML. Structural analysis
re-runs the import from the raw YAML and rejects edited/stale summaries; do not
hand-edit `results/summary.json`.

## Coupons to make

| IDs | Material / count | Nominal test-only part |
| --- | --- | --- |
| `MAT-FOAM3-01…03`, `MAT-FOAM5-01…03` | foam 3/5, 3 each | 100 x 100 density square; 200 x 200 optional foam |
| `MAT-POP2`, `MAT-BIRCH2`, `MAT-BIRCH3` | each plywood, 3 | 100 x 100 density/visual coupon |
| `PLY-BEND-*` | each plywood, 3 along + 3 across face grain | 240 x 25 strip |
| `PLY-BEAR-*` | birch2/birch3, 3 each; poplar2 optional | 100 x 30 with centred Ø3/4/5 hole |
| `GLUE-FF/FB/BB-*` | 3 per family | 160 x 25 single-lap, 25 x 25 overlap |
| `GLUE-CB-*` | 3 | 14-mm tube, 75-mm bond to 25 x 100 birch2 plate |
| `LW-RIB-TEST-*` | LW-PLA, 3 | 180 x 20 x 2 rib-like beam |
| `CARBON-SPAR-01` | actual 14 x 12 tube | inspect and reuse uncut for EI test |
| `SOCKET-01` | actual tube, rod, liner, sleeve, birch | representative central socket |
| `DBOX-A/B/C-01` | foam/birch/glue/reinforcement | 300-mm torsion article, root chord 250 |

All CAD exports are test-only, generated in mm, and have no kerf compensation
in nominal geometry. Sand/remove laser char and vacuum it before a structural
glue joint. Printed gauges are screening only: final fit uses actual measured
tube and precision rod.

## Foam density and indentation

Measure L/W, five thickness points (software minimum three), then mass. Density
is `mass_g * 1,000,000 / (L_mm * W_mm * mean_thickness_mm)` kg/m³. Test three
samples and record surface skins/cell direction/dents/water uptake.

For a comparative indentation metric, support a 150 x 150 foam piece on a flat
board, centre a rounded 25 x 25 flat indenter and apply 0.5/1.0/1.5/2.0 kg for
60 s each. Record indentation and recovery after 10 min unloaded. It is not a
modulus or compression allowable. Stop for puncture, cracks or cell collapse.
Unsupported 3-mm foam is not credited as a spar.

## Plywood density, bending and bearing

Record ply count, face grain, voids, delamination, warp and char. Density uses
the foam procedure. For bending place 240 x 25 strip on 25-mm rounded supports,
**200-mm clear span**, with a centred 25-mm shoe. Apply 2/4/6/8 N for 30 s,
unloading between steps; use a catch underneath. Test long/cross face grain.
The tool uses `EI = P L³/(48δ)` and effective E from measured section; R² must
be >=0.995 for stiffness use. Do not load to break.

For bearing, use 100 x 30 coupon, centred Ø3/Ø4/Ø5 hole and 25-mm edge distance.
A smooth bolt/washer in a guarded in-plane pull fixture shows first ovality,
splitting, crushing and net-section failure. Photograph both faces. Stop at a
crack, abrupt displacement or fixture slip. It compares birch2/birch3 for a
future boom detail; it is not a bolt allowable.

## LW-PLA stiffness and creep

Print three beams with 0.20-mm layers, 0.45-mm nominal line width, three walls,
2.0-mm rib body, 10–15% gyroid only around tabs/transitions and layers normal to
the rib plane. Record nozzle, temperature, flow/foaming setting, lot and mass;
the last three are user inputs. Test 1/2/3 N in the 200-mm bending fixture.

For creep, clamp 120 mm as a cantilever, add 1 N at the tip, and record initial,
10 min, 1 h, 4 h and 30-min recovered deflection. 40–50 C is optional only in
a supervised dedicated non-food thermostat box; never use a food oven. LW-PLA
remains optional until density, creep and interlayer observations are acceptable.

## Glue coupons and retained mass

Make three each foam–foam, foam–birch2, birch2–birch2 and carbon–birch2. Use
25 x 25 flat overlaps; carbon uses 75-mm prepared contact. Keep adhesive,
abrasion/cleaning, clamp pressure, cure and ambient identical. Weigh dry parts,
cure, reweigh; retained glue is `after - before`, aggregated as g/cm². Pull
slowly in a guarded fixture and record first slip/failure: `cohesive_foam`,
`adhesive_interface`, `plywood_delamination`, `carbon_interface`, `mixed` or
`no_failure`. First-slip/failure loads are entered as positive N values and
remain in the result. GLUE-GATE is explicit: `NOT_MEASURED` until every family
has three coupons; it fails for adhesive/carbon-interface modes. A spring scale
is comparative only and never creates a numerical joint allowable.

Every coupon needs applied-load evidence: `no_failure` requires a positive
`maximum_applied_load_n`; any observed failure requires positive
`first_slip_load_n` and/or `failure_load_n`. Failure modes are family-specific:
foam joints may be `cohesive_foam`; birch–birch may be
`plywood_delamination`; carbon–birch may be `plywood_delamination`,
`adhesive_interface` or `carbon_interface` but **never** `cohesive_foam`.
`mixed` requires at least two explicitly recorded, family-valid component modes;
it cannot hide an impossible mode. The YAML result retains all recorded loads
and modes for audit. GLUE-GATE evaluates both the headline and every mixed
component mode: therefore a carbon–birch `mixed` coupon containing
`adhesive_interface` or `carbon_interface` fails the gate.

## Carbon inspection and safe EI test

At 100-mm stations measure two perpendicular OD and, without damage, two ID
values. Measure known length/mass for g/m and straightness on a flat surface.
Current inspection screens are OD 14.00 +/-0.10, ID 11.85–12.10 and wall >=0.90;
they are not facts until measured.

Use uncut 800-mm tube on 25-mm saddles at **600-mm span**, centred 25-mm saddle,
mechanical catch and shielding. Apply known 5/10/15/20 N (about
0.51/1.02/1.53/2.04 kg) for 30 s. 20 N gives only 3.0 N m central moment and
about 24 MPa nominal stress: non-destructive, not a strength test. Record centre
deflection to 0.1 mm. R² >=0.995 is required. Valid EI can affect **deflection
only**, never tension/compression/shear allowables. Wear eye protection, stay
out of the bending plane, shield carbon splinters and capture hanging masses.

The spar geometry gate is also required before E may feed deflection: every
station must meet OD 13.90–14.10, ID 11.85–12.10, minimum wall >=0.90 and
ovality <=0.20 mm. Store all station/axis values; do not average away a failed
station. Measure the actual joiner rod at several stations, weigh known length
for g/m, then enter tube/rod fit pairs. Each radial clearance must be
0.075–0.175 mm; this completes DIMENSION-GATE only together with spar/rod gates.

## Socket and D-box proof articles

`SOCKET-01`: two actual tube segments >=325 mm, actual 600-mm rod with 275-mm
insertion each side, 50-mm central/support zone, 50-mm prepared liners/external
±45 sleeves, paired 50 x 50 birch2 plates with >=30-mm net ligament. This is
not a flight part. Use guarded opposed 250-mm torque arms, no foam. Current
100% root moment is 15.982 N m (6.52 kg at each 250-mm arm), but the structural
closeout proof is **1.25 x = 19.977 N m** (79.91 N / 8.15 kg equivalent per
arm). Test 25/50/75/100/125% with 60-s dwells. PASS requires that 1.25 proof,
no slip, crush, hoop split, delamination or plate crack, and <=0.10-mm residual
displacement. Any damage is STOP. This is a proof gate, not an ultimate strength
claim.

`DBOX-A/B/C`: actual root Clark-Y chord 250 mm, LE-to-spar 75 mm, 300-mm length,
ribs/bulkheads at 0/100/200/300. A is foam-only control; B continuous ±45 glass
80–110 g/m² candidate; C continuous ±45 carbon 80–120 g/m² candidate. Each has
foam3 skin, birch2 closure and actual adhesive. Clamp one end; use 250-mm arm
and guarded 0.5/1.0/1.5/2.0-kg masses. Measure pointer/scale (primary) and phone
inclinometer (check). `GJ = T L / theta`; R² >=0.995. Record constituent and
complete masses. Article GJ is **not** an effective material G.

For each D-box article record foam, ribs, closure, dry reinforcement,
adhesive/resin, **test-fixture mass** (end bulkheads/clamps) and complete mass.
`complete = flight-representative constituents + fixture mass` must reconcile.
The importer subtracts only the explicit fixture mass before conservative
root-article-per-metre scaling; never scale torque arms, external guards or end
fixture hardware into the wing budget.
In YAML these fields are `mass_breakdown_g.fixture_mass_g` and
`mass_breakdown_g.complete_article_mass_g`; the five flight-representative
constituents must also be recorded separately.

## Gates before production wing CAD

| Gate | Pass condition |
| --- | --- |
| SPAR-GATE | dimensions pass screens; linear EI corresponds to E >=70 GPa; strength evidence remains separate |
| DIMENSION-GATE | spar OD/ID/wall/ovality pass at every station; rod 11.50–11.70 and every radial clearance 0.075–0.175 mm |
| SOCKET-GATE | `SOCKET-01` survives 19.977 N m (1.25x) proof without damage/slip and <=0.10-mm residual |
| DBOX-GATE | reinforced article is linear and GJ >=22.8 N m²; separate from 300-MPa effective-G screen |
| GLUE-GATE | three documented repeats/family, no unacceptable adhesive/carbon-interface failure; no automatic allowable |
| MASS-GATE | re-run using density/spar g/m and article mass; final pass needs wing allocation not yet in YAML |

Mandatory: foam3/foam5/poplar2/birch2/birch3 density, spar inspection/EI,
foam–foam/foam–plywood/carbon–birch glue, socket proof, D-box GJ and mass-budget
rerun. LW-PLA is optional when it is not used in the first wing.

```bash
./tools/cad-shell.sh scripts/analyze_material_measurements.py
./tools/cad-shell.sh scripts/analyze_wing_structure.py --materials-results analysis/materials/results/summary.json --use-measured-stiffness --dbox-variant C
```

Density uses at least three specimens and retains mean/min/max/standard deviation;
the budget always propagates measured min/max, never collapses density scatter to
a point. The named D-box variant replaces overlapping planning portions with its
fixture-excluded, closed root-article mass conservatively scaled across 1.6 m.
Glue g/cm² remains `NOT_MEASURED` for wing mass until all four families have
three coupons and an explicit reproducible bond-area model is supplied. No safety
factor changes silently.

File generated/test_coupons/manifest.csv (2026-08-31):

id | material | quantity | purpose | warning | width_mm | height_mm | dxf | svg
MAT-DENS-100 | foam or plywood; cut n>=3 per material | 3 | density coupon | TEST-ONLY / NOMINAL / NO KERF / NOT FLIGHT PART | 100 | 100 | MAT-DENS-100.dxf | MAT-DENS-100.svg
MAT-DENS-200 | foam or plywood; cut n>=3 per material | 3 | density coupon | TEST-ONLY / NOMINAL / NO KERF / NOT FLIGHT PART | 200 | 200 | MAT-DENS-200.dxf | MAT-DENS-200.svg
PLY-BEND-240x25-POPLAR2-FACE-GRAIN-LONG | poplar 2 mm | 3 | three-point bending strip; face grain parallel to strip | TEST-ONLY / NOMINAL / NO KERF / NOT FLIGHT PART | 240 | 25 | PLY-BEND-240x25-POPLAR2-FACE-GRAIN-LONG.dxf | PLY-BEND-240x25-POPLAR2-FACE-GRAIN-LONG.svg
PLY-BEND-240x25-POPLAR2-FACE-GRAIN-CROSS | poplar 2 mm | 3 | three-point bending strip; face grain transverse to strip | TEST-ONLY / NOMINAL / NO KERF / NOT FLIGHT PART | 240 | 25 | PLY-BEND-240x25-POPLAR2-FACE-GRAIN-CROSS.dxf | PLY-BEND-240x25-POPLAR2-FACE-GRAIN-CROSS.svg
PLY-BEND-240x25-BIRCH2-FACE-GRAIN-LONG | birch 2 mm | 3 | three-point bending strip; face grain parallel to strip | TEST-ONLY / NOMINAL / NO KERF / NOT FLIGHT PART | 240 | 25 | PLY-BEND-240x25-BIRCH2-FACE-GRAIN-LONG.dxf | PLY-BEND-240x25-BIRCH2-FACE-GRAIN-LONG.svg
PLY-BEND-240x25-BIRCH2-FACE-GRAIN-CROSS | birch 2 mm | 3 | three-point bending strip; face grain transverse to strip | TEST-ONLY / NOMINAL / NO KERF / NOT FLIGHT PART | 240 | 25 | PLY-BEND-240x25-BIRCH2-FACE-GRAIN-CROSS.dxf | PLY-BEND-240x25-BIRCH2-FACE-GRAIN-CROSS.svg
PLY-BEND-240x25-BIRCH3-FACE-GRAIN-LONG | birch 3 mm | 3 | three-point bending strip; face grain parallel to strip | TEST-ONLY / NOMINAL / NO KERF / NOT FLIGHT PART | 240 | 25 | PLY-BEND-240x25-BIRCH3-FACE-GRAIN-LONG.dxf | PLY-BEND-240x25-BIRCH3-FACE-GRAIN-LONG.svg
PLY-BEND-240x25-BIRCH3-FACE-GRAIN-CROSS | birch 3 mm | 3 | three-point bending strip; face grain transverse to strip | TEST-ONLY / NOMINAL / NO KERF / NOT FLIGHT PART | 240 | 25 | PLY-BEND-240x25-BIRCH3-FACE-GRAIN-CROSS.dxf | PLY-BEND-240x25-BIRCH3-FACE-GRAIN-CROSS.svg
PLY-BEAR-100x30-POPLAR2-FACE-GRAIN-LONG | poplar 2 mm | 3 | bearing and hole-crushing coupon; face grain parallel to strip | TEST-ONLY / NOMINAL / NO KERF / NOT FLIGHT PART | 100 | 30 | PLY-BEAR-100x30-POPLAR2-FACE-GRAIN-LONG.dxf | PLY-BEAR-100x30-POPLAR2-FACE-GRAIN-LONG.svg
PLY-BEAR-100x30-POPLAR2-FACE-GRAIN-CROSS | poplar 2 mm | 3 | bearing and hole-crushing coupon; face grain transverse to strip | TEST-ONLY / NOMINAL / NO KERF / NOT FLIGHT PART | 100 | 30 | PLY-BEAR-100x30-POPLAR2-FACE-GRAIN-CROSS.dxf | PLY-BEAR-100x30-POPLAR2-FACE-GRAIN-CROSS.svg
PLY-BEAR-100x30-BIRCH2-FACE-GRAIN-LONG | birch 2 mm | 3 | bearing and hole-crushing coupon; face grain parallel to strip | TEST-ONLY / NOMINAL / NO KERF / NOT FLIGHT PART | 100 | 30 | PLY-BEAR-100x30-BIRCH2-FACE-GRAIN-LONG.dxf | PLY-BEAR-100x30-BIRCH2-FACE-GRAIN-LONG.svg
PLY-BEAR-100x30-BIRCH2-FACE-GRAIN-CROSS | birch 2 mm | 3 | bearing and hole-crushing coupon; face grain transverse to strip | TEST-ONLY / NOMINAL / NO KERF / NOT FLIGHT PART | 100 | 30 | PLY-BEAR-100x30-BIRCH2-FACE-GRAIN-CROSS.dxf | PLY-BEAR-100x30-BIRCH2-FACE-GRAIN-CROSS.svg
PLY-BEAR-100x30-BIRCH3-FACE-GRAIN-LONG | birch 3 mm | 3 | bearing and hole-crushing coupon; face grain parallel to strip | TEST-ONLY / NOMINAL / NO KERF / NOT FLIGHT PART | 100 | 30 | PLY-BEAR-100x30-BIRCH3-FACE-GRAIN-LONG.dxf | PLY-BEAR-100x30-BIRCH3-FACE-GRAIN-LONG.svg
PLY-BEAR-100x30-BIRCH3-FACE-GRAIN-CROSS | birch 3 mm | 3 | bearing and hole-crushing coupon; face grain transverse to strip | TEST-ONLY / NOMINAL / NO KERF / NOT FLIGHT PART | 100 | 30 | PLY-BEAR-100x30-BIRCH3-FACE-GRAIN-CROSS.dxf | PLY-BEAR-100x30-BIRCH3-FACE-GRAIN-CROSS.svg
GLUE-FF-LAP-160x25 | foam to foam | 3 | lap-joint strip; blue TEST_SCORE marks the 25x25 registration overlap | TEST-ONLY / NOMINAL / NO KERF / NOT FLIGHT PART | 160 | 25 | GLUE-FF-LAP-160x25.dxf | GLUE-FF-LAP-160x25.svg
GLUE-FB-LAP-160x25 | foam to birch 2 | 3 | lap-joint strip; blue TEST_SCORE marks the 25x25 registration overlap | TEST-ONLY / NOMINAL / NO KERF / NOT FLIGHT PART | 160 | 25 | GLUE-FB-LAP-160x25.dxf | GLUE-FB-LAP-160x25.svg
GLUE-BB-LAP-160x25 | birch 2 to birch 2 | 3 | lap-joint strip; blue TEST_SCORE marks the 25x25 registration overlap | TEST-ONLY / NOMINAL / NO KERF / NOT FLIGHT PART | 160 | 25 | GLUE-BB-LAP-160x25.dxf | GLUE-BB-LAP-160x25.svg
GLUE-CB-LAP-160x25 | carbon tube to birch 2 fixture stock | 3 | lap-joint strip; blue TEST_SCORE marks the 25x25 registration overlap | TEST-ONLY / NOMINAL / NO KERF / NOT FLIGHT PART | 160 | 25 | GLUE-CB-LAP-160x25.dxf | GLUE-CB-LAP-160x25.svg
SPAR-EI-CRADLE-14 | birch 3 | 2 | 14-mm spar support/centre saddle, drill/cut opening | TEST-ONLY / NOMINAL / NO KERF / NOT FLIGHT PART | 50 | 35 | SPAR-EI-CRADLE-14.dxf | SPAR-EI-CRADLE-14.svg
SPAR-EI-GUARDED-CATCH | birch 3 / foam padding | 2 | catch below spar; fixture only | TEST-ONLY / NOMINAL / NO KERF / NOT FLIGHT PART | 60 | 50 | SPAR-EI-GUARDED-CATCH.dxf | SPAR-EI-GUARDED-CATCH.svg
JOINER-ROUGH-RING-11.50 | 3D-print or laser test gauge | 1 | ROUGH fit indication only; verify actual rod by caliper | TEST-ONLY / NOMINAL / NO KERF / NOT FLIGHT PART | 24 | 24 | JOINER-ROUGH-RING-11.50.dxf | JOINER-ROUGH-RING-11.50.svg
JOINER-ROUGH-RING-11.60 | 3D-print or laser test gauge | 1 | ROUGH fit indication only; verify actual rod by caliper | TEST-ONLY / NOMINAL / NO KERF / NOT FLIGHT PART | 24 | 24 | JOINER-ROUGH-RING-11.60.dxf | JOINER-ROUGH-RING-11.60.svg
JOINER-ROUGH-RING-11.70 | 3D-print or laser test gauge | 1 | ROUGH fit indication only; verify actual rod by caliper | TEST-ONLY / NOMINAL / NO KERF / NOT FLIGHT PART | 24 | 24 | JOINER-ROUGH-RING-11.70.dxf | JOINER-ROUGH-RING-11.70.svg
JOINER-ROUGH-RING-11.80 | 3D-print or laser test gauge | 1 | ROUGH fit indication only; verify actual rod by caliper | TEST-ONLY / NOMINAL / NO KERF / NOT FLIGHT PART | 24 | 24 | JOINER-ROUGH-RING-11.80.dxf | JOINER-ROUGH-RING-11.80.svg
SOCKET-BIRCH2-PLATE | birch 2 | 4 | representative joiner/socket plate template | TEST-ONLY / NOMINAL / NO KERF / NOT FLIGHT PART | 120 | 45 | SOCKET-BIRCH2-PLATE.dxf | SOCKET-BIRCH2-PLATE.svg
SOCKET-GUARDED-FIXTURE | birch 3 fixture stock | 2 | shielded socket proof-test fixture side plate | TEST-ONLY / NOMINAL / NO KERF / NOT FLIGHT PART | 160 | 80 | SOCKET-GUARDED-FIXTURE.dxf | SOCKET-GUARDED-FIXTURE.svg
DBOX-A-RIB-X000 | foam 5 for ribs | 1 | 300-mm closed D-box bay end bulkhead at x=0 mm; variant A: foam-only control | TEST-ONLY / NOMINAL / NO KERF / NOT FLIGHT PART | 75.0 | 30.234 | DBOX-A-RIB-X000.dxf | DBOX-A-RIB-X000.svg
DBOX-A-RIB-X100 | foam 5 for ribs | 1 | 300-mm closed D-box bay internal rib at x=100 mm; variant A: foam-only control | TEST-ONLY / NOMINAL / NO KERF / NOT FLIGHT PART | 75.0 | 30.234 | DBOX-A-RIB-X100.dxf | DBOX-A-RIB-X100.svg
DBOX-A-RIB-X200 | foam 5 for ribs | 1 | 300-mm closed D-box bay internal rib at x=200 mm; variant A: foam-only control | TEST-ONLY / NOMINAL / NO KERF / NOT FLIGHT PART | 75.0 | 30.234 | DBOX-A-RIB-X200.dxf | DBOX-A-RIB-X200.svg
DBOX-A-RIB-X300 | foam 5 for ribs | 1 | 300-mm closed D-box bay end bulkhead at x=300 mm; variant A: foam-only control | TEST-ONLY / NOMINAL / NO KERF / NOT FLIGHT PART | 75.0 | 30.234 | DBOX-A-RIB-X300.dxf | DBOX-A-RIB-X300.svg
DBOX-A-BIRCH2-CLOSURE | birch 2 | 1 | spar closure raw height 29.247 mm + 2.5-mm test trim allowance; variant A: foam-only control | TEST-ONLY / NOMINAL / NO KERF / NOT FLIGHT PART | 300 | 31.747 | DBOX-A-BIRCH2-CLOSURE.dxf | DBOX-A-BIRCH2-CLOSURE.svg
DBOX-A-FOAM3-UPPER-SKIN | foam 3 | 1 | upper-surface developed root Clark-Y skin; variant A: foam-only control | TEST-ONLY / NOMINAL / NO KERF / NOT FLIGHT PART | 300 | 81.095 | DBOX-A-FOAM3-UPPER-SKIN.dxf | DBOX-A-FOAM3-UPPER-SKIN.svg
DBOX-A-FOAM3-LOWER-SKIN | foam 3 | 1 | lower-surface developed root Clark-Y skin; variant A: foam-only control | TEST-ONLY / NOMINAL / NO KERF / NOT FLIGHT PART | 300 | 77.82 | DBOX-A-FOAM3-LOWER-SKIN.dxf | DBOX-A-FOAM3-LOWER-SKIN.svg
DBOX-A-BIRCH3-END-BULKHEAD | birch 3 test-fixture material | 2 | stiff end bulkheads/clamp interfaces at x=0 and x=300; TEST ARTICLE ONLY | TEST-ONLY / NOMINAL / NO KERF / NOT FLIGHT PART | 75.0 | 30.234 | DBOX-A-BIRCH3-END-BULKHEAD.dxf | DBOX-A-BIRCH3-END-BULKHEAD.svg
DBOX-B-RIB-X000 | foam 5 for ribs | 1 | 300-mm closed D-box bay end bulkhead at x=0 mm; variant B: foam + light +/-45 glass candidate | TEST-ONLY / NOMINAL / NO KERF / NOT FLIGHT PART | 75.0 | 30.234 | DBOX-B-RIB-X000.dxf | DBOX-B-RIB-X000.svg
DBOX-B-RIB-X100 | foam 5 for ribs | 1 | 300-mm closed D-box bay internal rib at x=100 mm; variant B: foam + light +/-45 glass candidate | TEST-ONLY / NOMINAL / NO KERF / NOT FLIGHT PART | 75.0 | 30.234 | DBOX-B-RIB-X100.dxf | DBOX-B-RIB-X100.svg
DBOX-B-RIB-X200 | foam 5 for ribs | 1 | 300-mm closed D-box bay internal rib at x=200 mm; variant B: foam + light +/-45 glass candidate | TEST-ONLY / NOMINAL / NO KERF / NOT FLIGHT PART | 75.0 | 30.234 | DBOX-B-RIB-X200.dxf | DBOX-B-RIB-X200.svg
DBOX-B-RIB-X300 | foam 5 for ribs | 1 | 300-mm closed D-box bay end bulkhead at x=300 mm; variant B: foam + light +/-45 glass candidate | TEST-ONLY / NOMINAL / NO KERF / NOT FLIGHT PART | 75.0 | 30.234 | DBOX-B-RIB-X300.dxf | DBOX-B-RIB-X300.svg
DBOX-B-BIRCH2-CLOSURE | birch 2 | 1 | spar closure raw height 29.247 mm + 2.5-mm test trim allowance; variant B: foam + light +/-45 glass candidate | TEST-ONLY / NOMINAL / NO KERF / NOT FLIGHT PART | 300 | 31.747 | DBOX-B-BIRCH2-CLOSURE.dxf | DBOX-B-BIRCH2-CLOSURE.svg
DBOX-B-FOAM3-UPPER-SKIN | foam 3 | 1 | upper-surface developed root Clark-Y skin; variant B: foam + light +/-45 glass candidate | TEST-ONLY / NOMINAL / NO KERF / NOT FLIGHT PART | 300 | 81.095 | DBOX-B-FOAM3-UPPER-SKIN.dxf | DBOX-B-FOAM3-UPPER-SKIN.svg
DBOX-B-FOAM3-LOWER-SKIN | foam 3 | 1 | lower-surface developed root Clark-Y skin; variant B: foam + light +/-45 glass candidate | TEST-ONLY / NOMINAL / NO KERF / NOT FLIGHT PART | 300 | 77.82 | DBOX-B-FOAM3-LOWER-SKIN.dxf | DBOX-B-FOAM3-LOWER-SKIN.svg
DBOX-B-BIRCH3-END-BULKHEAD | birch 3 test-fixture material | 2 | stiff end bulkheads/clamp interfaces at x=0 and x=300; TEST ARTICLE ONLY | TEST-ONLY / NOMINAL / NO KERF / NOT FLIGHT PART | 75.0 | 30.234 | DBOX-B-BIRCH3-END-BULKHEAD.dxf | DBOX-B-BIRCH3-END-BULKHEAD.svg
DBOX-C-RIB-X000 | foam 5 for ribs | 1 | 300-mm closed D-box bay end bulkhead at x=0 mm; variant C: foam + +/-45 carbon candidate | TEST-ONLY / NOMINAL / NO KERF / NOT FLIGHT PART | 75.0 | 30.234 | DBOX-C-RIB-X000.dxf | DBOX-C-RIB-X000.svg
DBOX-C-RIB-X100 | foam 5 for ribs | 1 | 300-mm closed D-box bay internal rib at x=100 mm; variant C: foam + +/-45 carbon candidate | TEST-ONLY / NOMINAL / NO KERF / NOT FLIGHT PART | 75.0 | 30.234 | DBOX-C-RIB-X100.dxf | DBOX-C-RIB-X100.svg
DBOX-C-RIB-X200 | foam 5 for ribs | 1 | 300-mm closed D-box bay internal rib at x=200 mm; variant C: foam + +/-45 carbon candidate | TEST-ONLY / NOMINAL / NO KERF / NOT FLIGHT PART | 75.0 | 30.234 | DBOX-C-RIB-X200.dxf | DBOX-C-RIB-X200.svg
DBOX-C-RIB-X300 | foam 5 for ribs | 1 | 300-mm closed D-box bay end bulkhead at x=300 mm; variant C: foam + +/-45 carbon candidate | TEST-ONLY / NOMINAL / NO KERF / NOT FLIGHT PART | 75.0 | 30.234 | DBOX-C-RIB-X300.dxf | DBOX-C-RIB-X300.svg
DBOX-C-BIRCH2-CLOSURE | birch 2 | 1 | spar closure raw height 29.247 mm + 2.5-mm test trim allowance; variant C: foam + +/-45 carbon candidate | TEST-ONLY / NOMINAL / NO KERF / NOT FLIGHT PART | 300 | 31.747 | DBOX-C-BIRCH2-CLOSURE.dxf | DBOX-C-BIRCH2-CLOSURE.svg
DBOX-C-FOAM3-UPPER-SKIN | foam 3 | 1 | upper-surface developed root Clark-Y skin; variant C: foam + +/-45 carbon candidate | TEST-ONLY / NOMINAL / NO KERF / NOT FLIGHT PART | 300 | 81.095 | DBOX-C-FOAM3-UPPER-SKIN.dxf | DBOX-C-FOAM3-UPPER-SKIN.svg
DBOX-C-FOAM3-LOWER-SKIN | foam 3 | 1 | lower-surface developed root Clark-Y skin; variant C: foam + +/-45 carbon candidate | TEST-ONLY / NOMINAL / NO KERF / NOT FLIGHT PART | 300 | 77.82 | DBOX-C-FOAM3-LOWER-SKIN.dxf | DBOX-C-FOAM3-LOWER-SKIN.svg
DBOX-C-BIRCH3-END-BULKHEAD | birch 3 test-fixture material | 2 | stiff end bulkheads/clamp interfaces at x=0 and x=300; TEST ARTICLE ONLY | TEST-ONLY / NOMINAL / NO KERF / NOT FLIGHT PART | 75.0 | 30.234 | DBOX-C-BIRCH3-END-BULKHEAD.dxf | DBOX-C-BIRCH3-END-BULKHEAD.svg
DBOX-TORQUE-ARM-250 | birch 3 test-fixture material | 1 | 250-mm torque arm for closed-cell GJ test; fixture only | TEST-ONLY / NOMINAL / NO KERF / NOT FLIGHT PART | 250 | 25 | DBOX-TORQUE-ARM-250.dxf | DBOX-TORQUE-ARM-250.svg
DBOX-GUARDED-TORSION-FIXTURE | birch 3 test-fixture material | 2 | guarded fixed/free-end fixture plates for closed-cell torsion test | TEST-ONLY / NOMINAL / NO KERF / NOT FLIGHT PART | 140 | 100 | DBOX-GUARDED-TORSION-FIXTURE.dxf | DBOX-GUARDED-TORSION-FIXTURE.svg
LW-RIB-TEST-180x20 | LW-PLA print reference | 3 | 180x20x2 rib-like coupon with 10-mm end tabs; see print manifest | TEST-ONLY / NOMINAL / NO KERF / NOT FLIGHT PART | 180 | 20 | LW-RIB-TEST-180x20.dxf | LW-RIB-TEST-180x20.svg

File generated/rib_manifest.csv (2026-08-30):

id | station_mm | chord_mm | washout_deg | dihedral_z_mm | spar_x_mm | spar_z_mm | material | thickness_mm
R00 | 0.000 | 250.000 | -0.0000 | 0.000 | 75.000 | 8.047 | birch plywood (root reinforcement) | 2.000
R01 | 100.000 | 243.750 | -0.1875 | 3.492 | 73.125 | 7.805 | foam | 5.000
R02 | 200.000 | 237.500 | -0.3750 | 6.984 | 71.250 | 7.565 | foam | 5.000
R03 | 300.000 | 231.250 | -0.5625 | 10.476 | 69.375 | 7.328 | foam | 5.000
R04 | 400.000 | 225.000 | -0.7500 | 13.968 | 67.500 | 7.092 | foam | 5.000
R05 | 500.000 | 218.750 | -0.9375 | 17.460 | 65.625 | 6.859 | foam | 5.000
R06 | 600.000 | 212.500 | -1.1250 | 20.952 | 63.750 | 6.628 | foam | 5.000
R07 | 700.000 | 206.250 | -1.3125 | 24.445 | 61.875 | 6.399 | foam | 5.000
R08 | 800.000 | 200.000 | -1.5000 | 27.937 | 60.000 | 6.172 | foam | 5.000

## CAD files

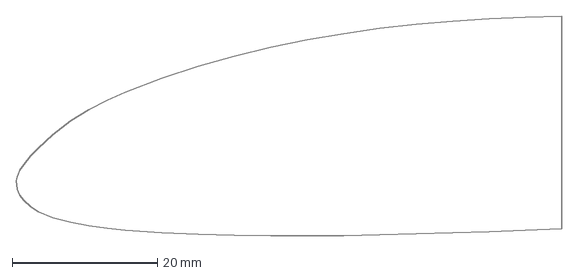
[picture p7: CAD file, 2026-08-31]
generated/test_coupons/DBOX-C-RIB-X300.dxf
75.0 x 30.2 mm

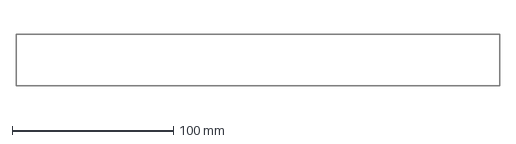
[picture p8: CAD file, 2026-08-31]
generated/test_coupons/DBOX-B-BIRCH2-CLOSURE.dxf
300.0 x 31.7 mm

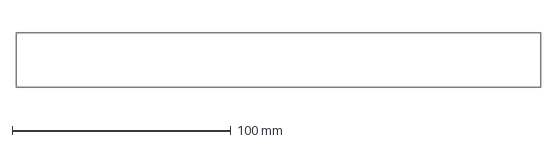
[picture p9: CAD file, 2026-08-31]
generated/test_coupons/PLY-BEND-240x25-POPLAR2-FACE-GRAIN-LONG.dxf
240.0 x 25.0 mm

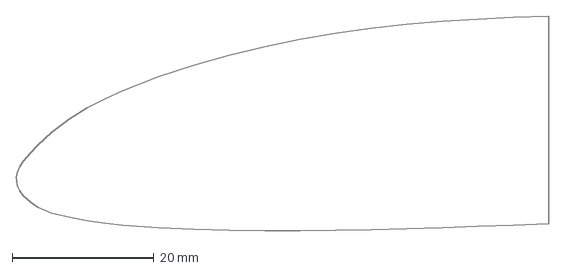
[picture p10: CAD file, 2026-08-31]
generated/test_coupons/DBOX-C-RIB-X100.dxf
75.0 x 30.2 mm

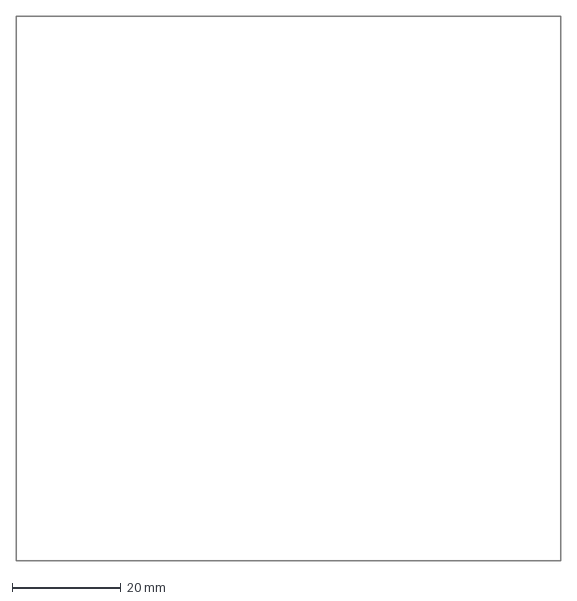
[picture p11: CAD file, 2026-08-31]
generated/test_coupons/MAT-DENS-100.dxf
100.0 x 100.0 mm

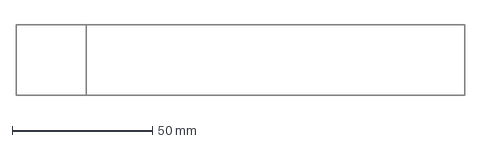
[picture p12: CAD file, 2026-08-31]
generated/test_coupons/GLUE-CB-LAP-160x25.dxf
160.0 x 25.0 mm

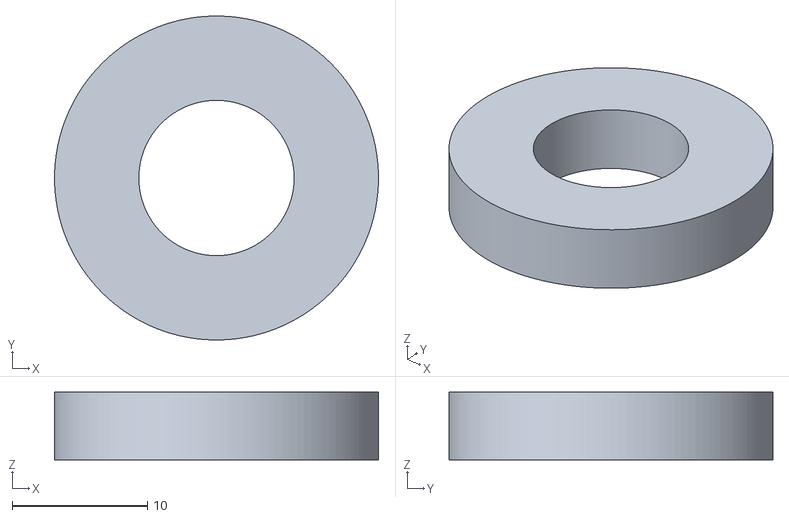
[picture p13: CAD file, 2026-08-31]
generated/test_coupons/JOINER-ROUGH-RING-11.50.stl
24.0 x 24.0 x 5.00

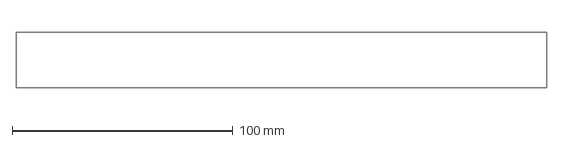
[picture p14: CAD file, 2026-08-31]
generated/test_coupons/PLY-BEND-240x25-BIRCH2-FACE-GRAIN-CROSS.dxf
240.0 x 25.0 mm

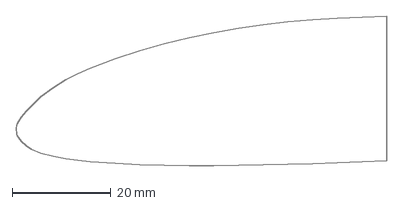
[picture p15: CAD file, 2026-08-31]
generated/test_coupons/DBOX-A-RIB-X300.dxf
75.0 x 30.2 mm

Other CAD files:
generated/rib_03_station_300.dxf
generated/rib_06_station_600.dxf
generated/rib_00_root.dxf
generated/rib_07_station_700.dxf
generated/rib_05_station_500.dxf
generated/rib_01_station_100.dxf
generated/rib_02_station_200.dxf
generated/rib_08_tip.dxf
generated/rib_04_station_400.dxf
generated/test_coupons/DBOX-A-BIRCH2-CLOSURE.dxf
generated/test_coupons/DBOX-A-BIRCH3-END-BULKHEAD.dxf
generated/test_coupons/DBOX-A-FOAM3-LOWER-SKIN.dxf
generated/test_coupons/DBOX-A-FOAM3-UPPER-SKIN.dxf
generated/test_coupons/DBOX-A-RIB-X000.dxf
generated/test_coupons/DBOX-A-RIB-X100.dxf
generated/test_coupons/DBOX-A-RIB-X200.dxf
generated/test_coupons/DBOX-B-BIRCH3-END-BULKHEAD.dxf
generated/test_coupons/DBOX-B-FOAM3-LOWER-SKIN.dxf
generated/test_coupons/DBOX-B-FOAM3-UPPER-SKIN.dxf
generated/test_coupons/DBOX-B-RIB-X000.dxf
generated/test_coupons/DBOX-B-RIB-X100.dxf
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

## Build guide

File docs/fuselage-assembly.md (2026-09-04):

# LR1600 Fuselage Prototype v1 — dry-build and bonding sequence

**Status:** prototype procedure.  Follow the generated part IDs and drawings;
stop when a datum cannot be met rather than forcing a tab, a longeron or a
boom.  The aircraft datum is wing root leading edge, +X aft, Y=0 symmetry
plane.  The wing interface plane, boom axes (Y=+/-230), motor axis and landing
contact reference are inspected assembly datums, not cosmetic shell references.

## Materials and controls

- Use the measured actual 2-mm and 3-mm birch sheets that passed the kerf/fit
  coupon.  Keep grain/orientation marking visible until the relevant proof is
  complete.
- Structural wood bonds: an aircraft-suitable epoxy selected for the actual
  material/cure environment.  Prepare charred laser edges to sound wood,
  abrade carbon, solvent-clean only with a compatible process, then de-dust.
  Record adhesive, batch, mix, cure temperature/time and retained mass.
- Use non-structural flexible adhesive only for shell, mesh, fairings and
  chafe protection; it does not replace structural epoxy in a load path.
- Carbon longerons are dry-trialled and marked before mix.  Full-area saddles,
  shaped cauls and tape/soft clamps prevent point crushing; no clamp may bend a
  longeron against its natural line.
- No printed item, shell or hatch is used as an alignment datum or temporary
  structural substitute.

## Mandatory dry assembly

1. Make the 2-mm/3-mm calibration coupons; measure actual material and
   nominal-to-finished tab/slot clearance.  Apply compensation only in the
   laser job.  Inspect all `PROTOTYPE CUTTABLE` parts and compare them to the
   cut manifest.
2. On a flat datum board establish X=0, the Y=0 centreline and the wing
   interface plane.  Install removable laser-cut locator fences/blocks.
3. Dry-fit lower keel, side members and all normal formers, then the X=-285
   `FUS-NOSE-INDEX-*`, X=+65…+200 `FUS-GEAR-*` and X=+285/+365 boom/motor
   station members. Verify no part is inverted and
   that all four longeron grooves are continuous by passing sacrificial 5 x
   3-mm stock through them.
4. Install the wing-side mating gauges; check the two interface frames are
   square to Y=0 and repeatable after removal/refit.  Do not infer wing load
   approval from this check.
5. Install the two boom alignment fixtures at X=+285 and X=+365. Establish
   Y=+/-230 at both stations, equal X station separation, and the defined
   motor axis.  Measure before every bond phase and record the values.
6. Trial the GFRP main-leg dummy/root with 3.0, 3.5 and 4.0-mm shim sets;
   verify accessible fasteners and removal path.  Trial the real nose strut
   tang in its 12-mm keyed root, with the wheel pointing straight ahead.
7. Trial the 155 x 75 x 28 dummy pack over its full X=-387.5...-332.5 useful
   range, including the `FUS-BAT-FINE-CLAMP-*` positions for exact 24% and
   25% CG. With all simulated FC/wire objects installed, disconnect it and
   lift it through the hatch/removal volume.  Check the two strap paths,
   forward/aft stops, finger/tool access and connector service loop.
8. Trial the motor-plate gauge and 13-in prop disk at the specified gear
   compression/rough-field fixtures.  The disk is tooling only.

No adhesive is mixed until these checks pass.  Record an exception and resolve
it in source CAD/configuration before cutting a replacement; do not file a
primary slot ad hoc.

## Bond order

1. Bond the central lower keel, side rails and X=-55/+65/+130 central skeleton on
   the datum board.  Use removable datum fences and verify centreline/twist
   before cure.
2. Bond the paired lower longerons continuously from the front battery/nose
   region through the wing and main-gear box.  Allow full cure in the designed
   cauls before loading the skeleton.
3. Bond the X=-285 lower-keel/nose-index structure and the `FUS-BAT-*` stop/rail
   load path.  The strut and printed fairings are not bonded in this step.
4. Bond main-gear double-shear box closure webs and the fixed spreader support
   structure.  Install only removable shims, leg and service fasteners after
   cure so a failed leg can be replaced.
5. Bond upper longerons, hatch perimeter rails and the remaining torsion/shear
   webs.  Re-check that the hatch opening stays clear and that the pack dummy
   still removes vertically.
6. Bond the X=+285/+365 boom/motor stations and the fixed motor cross-member using the boom/motor
   fixture.  Do not set boom clamp torque or bond a tube until its liner/coupon
   data exists.
7. Install serviceable servo/equipment supports, linkage guides and wire
   tie-point structure.  Verify that all screws and tensioners remain
   reachable; these items must not block pack extraction.
8. Reinspect straightness, wing-interface plane, boom symmetry, motor axis,
   gear geometry and hatch service.  Only after these checks add removable
   shell panels, skid, camera hardware and cooling guards.

## Hold points and acceptance at each irreversible step

| Hold point | Record / pass condition |
| --- | --- |
| Dry skeleton | Diagonals, Y=0 and longeron-groove continuity agree with drawing; no forced tab. |
| Lower-longeron cure | Both lines continuous, fully supported and free of visible void/peel; no high-bay butt joint. |
| Gear boxes | Main dummy and nose keyed strut install/remove without destruction; no reliance on a printed primary part. |
| Battery bay | Full dummy sweep, guarded disconnect, vertical hatch removal, strap routing and both stop paths demonstrated. |
| Boom/motor bond | Fixture record proves Y=+/-230, station separation and motor axis before cure; clamp remains `NOT RELEASED` without tube coupon. |
| Final skeleton | Wing gauges repeat; booms, motor and gear geometry meet drawing; proof articles passed or are explicitly pending. |

Expected initial failure modes are plywood bearing/splitting, unprepared
carbon-bond peel, GFRP root delamination, local boom clamp crushing and
motor-plate bolt bearing.  A crack, permanent set, delamination, bond line
opening, unexplained alignment shift or clamp slip is a stop condition.  Do
not mask it with shell, filler or a larger washer: record it and revise/prove
the underlying load path.

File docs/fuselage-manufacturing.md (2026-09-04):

# LR1600 Fuselage Prototype v1 — manufacturing definition

**Status:** `PROTOTYPE CUTTABLE` only where the generated `cad/fuselage_prototype`
manifest says so.  This is a structural prototype, not a production release or
a substitute for the proof programme in [fuselage-proof-plan.md](fuselage-proof-plan.md).
All dimensions are nominal mm in the wing-root-LE aircraft datum.  The CAD and
its typed `fuselage_prototype` configuration are the sole geometry source;
this document records function, material and process requirements and does
not override CAD dimensions.

## Structural classification and load paths

| Group | Classification | Function / load path | Material rule |
| --- | --- | --- | --- |
| Normal station formers, partial nose U-webs, side shear webs, lower keel, battery rail side-members, hatch perimeter rails | **PRIMARY STRUCTURE** | Close the plywood/carbon semi-monocoque, stabilize longerons, transmit distributed body shear and battery loads. | 2-mm birch.
| `FUS-NOSE-INDEX-BLOCK` / `FUS-NOSE-INDEX-DOUBLER`; `FUS-GEAR-DOUBLER-*`, `FUS-GEAR-SPREADER-*`, `FUS-GEAR-CLAMP-LAND`; `FUS-BAT-*-STOP` / `FUS-BAT-STRAP-ANCHOR-*`; `FUS-MOTOR-PLATE` | **PRIMARY STRUCTURE** | Local bearing, clamp reaction, double-shear and concentrated load transfer. | 3-mm birch only; see table below.
| Four 5 x 3 carbon longerons | **PRIMARY STRUCTURE** | Continuous fuselage bending paths.  Plywood webs transfer shear between them. | Actual 5 x 3-mm stock; no centreline-only substitute.
| Motor adapter plate, metal/G10 clamp spreaders, bolts/pins, non-crushing boom liner | **PRIMARY STRUCTURE** where specified by the assembly drawing | Transfer a concentrated reaction; removable items remain replaceable. | Selected material and proof only; a printed version is forbidden as flight structure.
| Hatch lid, light shell, camera bezel, cooling duct/mesh, electronics deck, cable clips, lower skid | **SECONDARY STRUCTURE** or **FAIRING / NON-STRUCTURAL** | Enclosure, service, dirt exclusion, local support, sacrificial protection.  They receive no wing, boom, battery, motor or gear load credit. | Foam/light laminate or print as assigned in the manifest.
| Datum board, boom/tail alignment fixture, propeller disk, calibration coupon, drill guides and dummy pack | **JIG / TOOLING** | Assembly or proof only. | Never fly.

The body is not a foam monocoque.  Its primary paths are: wing interface into
the X=-55/+65 transfer stations, through the longerons and closed central
webs; one-main landing reaction through the X=+65…+200 `FUS-GEAR-*`
double-shear box into both lower longerons and the upper closure web; nose
reaction from the X=-285 index through the lower keel to the X=-55 transfer
station; battery stops and strap anchors into the lower keel and
`FUS-HATCH-RAIL-*`; boom/motor reactions through the separated
X=+285/+365 stations.  A shell, printed part, adhesive-only tube joint, single
former or hatch never closes any of these paths.

## Birch selection and exact justification

| Nominal thickness | Parts / regions | Why this thickness is justified |
| --- | --- | --- |
| 2 mm birch | ordinary formers; partial `N170` rail former; lower keel; left/right side webs; gear-box closure webs; battery cradle/side rails; hatch perimeter rings; longitudinal interlocking members | These are distributed shear, torsion-closure and shape-stabilising members.  Their job is web action and controlled tab-and-slot assembly, not isolated bolt bearing.  Laser-cut char is removed wherever they bond structurally.
| 3 mm birch | `FUS-NOSE-INDEX-BLOCK`/`FUS-NOSE-INDEX-DOUBLER`; `FUS-GEAR-DOUBLER-*`, `FUS-GEAR-SPREADER-*` and `FUS-GEAR-CLAMP-LAND`; `FUS-MOTOR-PLATE`; `FUS-BAT-FWD-STOP`, `FUS-BAT-AFT-STOP` and `FUS-BAT-STRAP-ANCHOR-*` | These parts see concentrated bearing, compression, clamp, bolt/pin or stop reaction. They spread it into 2-mm webs and the carbon longerons. They must not be replaced by printed plastic. The TBD-tube `FUS-BOOM-SADDLE-*` placeholders are 3-mm but explicitly `NOT RELEASED`.

No other primary fuselage plywood part is promoted to 3 mm merely to make the
prototype easier to handle.  The required bearing/net-section coupon and the
representative proof articles determine whether any local doubling is needed.

## Carbon longerons and bonding

Install four pultruded 5 x 3-mm carbon longerons as actual rectangular stock,
with their broad 5-mm face bonded to prepared plywood groove faces.  The CAD
defines their station-by-station location and cut lengths; the planned paths
are deliberately continuous through the wing and main-gear bay:

| Path | Nominal X run | Nominal cut length before fit allowance | Purpose |
| --- | ---: | ---: | --- |
| Lower left / lower right | -475 to +365 at Y=+/-67.5, Z=-70 | 840 mm each, cut 10 mm long for trim | Nose-keel/battery-stop to wing, main gear and boom/motor bending continuity. |
| Upper left / upper right | -170 to +410 at Y=+/-67.5, Z=+62 | 580 mm each, cut 10 mm long for trim | Close the central bending couple from battery/hatch side rails through wing, gear and boom/motor bay. |

Cut stock long, trial-fit dry, then trim only after the datum-board check; do
not introduce a butt joint in `-55 <= X <= +200`.  Any necessary scarf is
outside that high-bending bay, has an overlap of at least 50 mm, and is a
separate coupon/proof subject.  A longeron termination is a tapered plywood
load-transfer region, never a square end against a web.  Carbon bonding faces
are abraded, solvent-cleaned and de-dusted; laser-charred birch faces are
sanded to sound wood.  Clamp pressure must wet the joint without squeezing it
dry.  Isolate carbon from any aluminium spreader/plate by a non-absorbing G10,
glass or polymer barrier and prevent a galvanic water path.

## Battery bay and retention

The bay accepts the P60B dummy/pack envelope **155 x 75 x 28 mm**. Its useful
centre-X range is -387.5 to -332.5 (55 mm): this is the former 50-mm range
extended 5 mm forward, without extending the nose. `FUS-BAT-RAIL-*` provides
six coarse 11-mm indexes; paired primary `FUS-BAT-FINE-CLAMP-*` parts have
55 x 4.2-mm continuous slots, so the `FUS-BAT-AFT-STOP` can lock the exact
measured-CG position between coarse indexes. Final CG uses the measured pack
centre, not a nominal scale mark. The swept pack envelope is X=-465 to -255.
The top hatch clear opening and its CAD removal solid must
enclose that sweep plus connector/service clearance, so removal is vertically
upward after disconnect and requires no wing removal.

Retention is deliberately redundant and never uses hook-and-loop friction,
foam compression, hatch strength or the connector as a load path:

1. A 3-mm birch forward stop takes the full forward proof reaction into the
   lower keel and both lower longerons.
2. A separately attached 3-mm `FUS-BAT-AFT-STOP`, captured by both fine clamps,
   takes the full aft proof reaction at every continuous setting; it is not
   merely a rail-end screw.
3. Two independent 20-mm straps pass through 3-mm anchor plates.  Each full
   strap/anchor path is sized and proofed for the full vertical 44.4-N proof
   reaction; their two paths provide retention redundancy rather than an
   assumed half-load share.
4. 2-mm birch side rails / broad non-compressive cradle locate the pack
   laterally.  Their fastener/adhesive path returns reaction to the keel, not
   the shell.

For a 503-g dummy at the 6-g operational assumption and 1.5 proof multiplier,
the proof reaction is `0.503 * 9.80665 * 6 * 1.5 = 44.4 N` in every principal
direction.  The forward five-millimetre improvement makes the prior exact
24%-MAC battery coordinate (-384.78 mm) physically within rail travel;
post-CAD ledger recomputation remains authoritative.

## Landing gear interfaces

### Removable GFRP main legs

The selected root is a 3-mm birch **double-shear cassette** from X=+65 to
+200: `FUS-GEAR-DOUBLER-*`, `FUS-GEAR-SPREADER-*` and
`FUS-GEAR-CLAMP-LAND` close a 2-mm upper closure web and two 2-mm side shear
webs. The leg is clamped over a long, rounded root land by replaceable metal/G10 spreaders and
through-bolts; it is not retained by a plywood slot, friction alone or printed
cheeks.  The local cassette attaches to both lower longerons and the upper
closure before it meets the secondary shell.  The leg is removable outboard /
downward after the accessible fasteners are removed; replace its sacrificial
leg before disturbing the fuselage box.

The prototype cassette accepts **3.0, 3.5 and 4.0-mm** GFRP laminates. The
3.0-mm specimen fits its nominal land; paired 0.5-mm `FUS-GEAR-SHIM-3P5` or
1.0-mm `FUS-GEAR-SHIM-4P0` PETG/G10 inserts set the 3.5/4.0-mm proof fit.
These are non-primary full-contact, hard inserts trapped by the spreader, not
load-bearing printed wedges. The leg width, root clamp length, hole size/edge distance and
bolt torque are controlled by the CAD drawing and must be checked against the
actual laminate coupon before drilling a leg.  Prove the assembled cassette to
121 N vertical on one main and 35 N each lateral/longitudinal; likely first
failure is leg-root delamination or birch bearing/splitting, not the shell.

### Fixed, non-steerable nose gear

`FUS-NOSE-INDEX-BLOCK` plus the two `FUS-NOSE-INDEX-DOUBLER` parts form a
captured **12-mm keyed root** in the X=-285 3-mm lower-keel box. A mating non-printed metal
strut tang bears on the flat faces of this key; the separate capture bolt only
retains the strut. Consequently yaw torque follows `strut tang -> keyed block
and doubler -> lower-keel web -> lower keel -> lower longerons`, rather than clamp
friction.  The index has manual straight-ahead fitting reference faces, but no
yaw degree of freedom after its capture hardware is tightened.

There is no steering arm, linkage, servo, saver, cable or steering mechanism.
The fork/strut is replaceable and retains the existing 75-mm wheel axle for a
pitch-only nose ski; the root key remains engaged so yaw stays locked.  Test
the real key/root at 60 N vertical and 35 N lateral plus 35 N longitudinal,
then record residual heading and inspect key-face crush, splitting and slip.

## Boom and motor interfaces

Two primary boom stations, X=+285 and X=+365, are exactly 80 mm apart. Each
has a `FUS-BOOM-SADDLE-*` 3-mm placeholder frame, a replaceable compliant
non-conductive saddle/liner and paired captured fasteners.  The two stations
provide longitudinal position and yaw anti-rotation; neither a single bolt nor
adhesive carries primary boom load.  Tightening is controlled by measured
torque after a representative tube/liner coupon establishes the safe clamp
limit.  The clamp must retain a replaceable boom without point-load crushing.

Boom tube OD, wall, laminate and supplier allowables are still unselected in
the typed source; therefore the contact saddle and torque setting are
`NOT RELEASED` even if the fuselage-side frames are cuttable.  Build the boom
coupon before crediting coupled wing/boom bending.  Fixture both boom axes at
Y=+/-230 and the tail reference while bonding; target station coordinates are
within +/-0.5 mm and differential tail incidence is <=0.25 degrees after
proof.

The motor uses the X=+365 structural frame and fixed cross-member with a
replaceable flat plate/adapter.  The plate has two shear keys plus accessible
through-fasteners; its adapter pattern remains provisional for the selected
50-mm-class motor.  No printed plate is flight structure.  The prototype
screen remains 15.1 N axial, 1.26 N m torsion and 0.64 N m inertia bending;
replace this screen with selected-motor measured thrust/torque before release.

## Laser-cut and assembly controls

CAD is nominal: it contains **no kerf compensation**.  Before cutting parts,
measure actual thickness at multiple points and cut the 2-mm and 3-mm tab/slot
calibration coupons in the same orientation/process.  Choose downstream
LightBurn kerf/fit compensation from measured results, retain the coupon, and
do not edit CAD to compensate for one machine.  Reject parts with delamination,
excessive char in a glue land, materially undersized ligament, broken small tab
or an out-of-tolerance slot.

Use tab-and-slot only for registration.  Critical stations include asymmetric
keying so they cannot be reversed; do not hammer a fitted tab into a stressed
slot.  Internal corners receive relief only where a rectangular tab actually
bottoms; all primary bolt/pin edge distances are CAD-checked.  Dry-assemble on
the datum board before adhesive.  The datum board, boom fixture, prop disk,
dummy battery and all printed drill/alignment aids are tooling and excluded
from aircraft mass.

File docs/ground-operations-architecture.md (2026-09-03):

# LR1600 Ground Operations Architecture v3

This supersedes the earlier 2,400-g ground screen. It is a preliminary 2,600-g integration design for dirt, compact soil and grass: wheels in summer and axle-mounted skis in winter. It does not alter wing geometry or claim certification.

Selected serviceable configuration: individually replaceable GFRP main spring legs, 105-mm mains and a 75-mm nose wheel on a replaceable sprung/compliant strut and fork. The nose wheel is fixed on aircraft +X by a positive anti-rotation mechanical index, with no steering linkage or yaw degree of freedom. Contacts are main X=+125, Y=+/-175 and nose X=-250: wheelbase=375 mm, track=350 mm, static nose share=13--17% over the design CG band. The 3-mm birch main box uses frames +65/+130/+200; the 3-mm nose keel box uses -285/-170/-55. Carbon longerons bridge them. Foam, outer skin and printed fairings have no primary-load credit.

The 13x10 pusher at X=+430, Z=+50 retains **66.9-mm** full-rough tip clearance with 105-mm wheels: 18-mm compression, 8-deg tail-low, one-main roll sensitivity, 20-mm rut and 5-mm wear/build are included. Corrected 100-mm wheels give 64.4 mm: above the 60-mm minimum but below the preferred 65-mm margin. The 14-in prop is a secondary case at approximately 54.2 mm and is not a rough-field baseline.

The governing main hardpoint proof is 121 N vertical at one wheel; nose proof is 60 N vertical and both sites receive 35 N lateral/longitudinal proof. Test complete bays, not a plywood coupon. The wheel configuration is a 196-g estimate; winter skis/retained legs are a 232-g estimate after deleting the former 6-g steering-only allowance. Main and nose ski pivots reuse exactly the wheel axles/hardpoints, with metal bushes, tip-up straps and positive nose-down stops. The nose ski may pitch about its axle but remains yaw-locked by the strut-root index. See [landing-gear.md](landing-gear.md) for calculations, failure modes and release gates.

Lower nose/pack/antenna protection is a replaceable skid/bumper, recessed FPV window and grommeted strain-relieved penetrations. Replace a bent leg, axle or damaged skid rather than accepting permanent set or bond damage after a rough impact.

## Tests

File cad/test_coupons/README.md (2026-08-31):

# LR1600 material and structural test coupons

These are **TEST-ONLY, NOMINAL, NO-KERF** files.  They are not aircraft
production parts and must never be substituted for flight structure.  All
dimensions are mm.  Generate with `python scripts/generate_test_coupons.py`.

The test dimensions live in `parameters.yaml`; only the D-box root Clark Y
outline and 30%-chord spar location are loaded from the typed aircraft loader.
The generated manifest identifies material, quantity and intended use.  Laser
operators must apply any kerf process settings outside the source geometry.

For a D-box article, record the whole assembled test-cell mass and separately
record `fixture_mass_g`: birch-3 end bulkheads/clamps and all torque-fixture
parts are test-fixture-only.  Only `flight_representative_mass_g` (complete
article minus fixture mass) may be supplied to a wing mass-budget workflow.

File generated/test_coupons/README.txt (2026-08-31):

TEST-ONLY / NOMINAL / NO KERF / NOT FLIGHT PART
Generated from cad/test_coupons/parameters.yaml. DBOX root profile/chord/spar and all developed dimensions come only from typed config/aircraft.yaml.

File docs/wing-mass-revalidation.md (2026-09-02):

# LR1600 wing mass revalidation — 2600 g preliminary sensitivity

## Scope and disposition

**Disposition: PASS CONDITIONAL.** Existing LR1600 wing geometry and structural
concept are conditionally acceptable for a **2600-g preliminary design case**
without structural redesign. This is not a production release, MTOW change, or
ultimate-strength claim.

`config/aircraft.yaml` remains source of truth: `aircraft.target_mass_g` is
**2400 g** and `design_load_factor_g` is **4.0**. The 2600-g case is only an
in-memory override in the reproducible analyses. Airfoil, planform, washout,
dihedral, spar, joiner/socket, ribs, D-box and boom-attachment concepts are
unchanged; no automatic reinforcement was made.

Run:

```bash
./tools/cad-shell.sh scripts/analyze_wing_aero_mass_sensitivity.py
./tools/cad-shell.sh scripts/analyze_wing_mass_revalidation.py
```

Outputs: [aero JSON](../analysis/aero/mass_sensitivity_2400_2600.json),
[aero CSV](../analysis/aero/mass_sensitivity_2400_2600.csv), structural
[summary](../analysis/wing_mass_revalidation/summary.json), and
[comparison](../analysis/wing_mass_revalidation/comparison.csv).

## Aero revalidation

Existing direct XFOIL polars, the 40-station finite-wing stall solver and
`wing_drag_n` were reused. Wing-only drag excludes fuselage, tail, pusher,
gaps and full-aircraft CdA. Ncrit=5 direct-polar gaps remain, so realistic
stall values are engineering sensitivities rather than new strict stall roots.

| Metric | 2400 g | 2600 g |
|---|---:|---:|
| Wing loading, g/dm² | 66.67 | 72.22 |
| Required CL at 50 / 60 / 70 / 80 / 90 km/h | .553 / .384 / .282 / .216 / .171 | .599 / .416 / .306 / .234 / .185 |
| Clean finite-wing stall, km/h | 34.49 | 35.91 |
| Nominal realistic engineering stall, km/h | 35.05 | 36.48 |
| Conservative realistic engineering stall, km/h | 37.55 | 39.09 |
| 99%-of-best wing-only L/D band, km/h | 56–64 | 59–67 |

At 50 / 60 / 70 / 80 / 90 km/h, induced drag is .648 / .450 / .331 / .253 /
.200 N at 2400 g and .760 / .528 / .388 / .297 / .235 N at 2600 g. Total wing
drag is 1.083 / 1.000 / 1.075 / 1.279 / 1.534 N and 1.197 / 1.074 / 1.108 /
1.295 / 1.544 N respectively. The speed shift follows `sqrt(2600/2400) =
1.0408`; it is not a new aircraft optimum. No approved approach multiplier
exists; any future `Vapp/Vstall` policy must retain its multiplier, with all
stall-referenced speeds increasing 4.08%.

## Four-g structural revalidation

The existing design/limit interpretation and elliptic per-console distribution
are retained; no ultimate factor is introduced.

| Metric | 2400 g | 2600 g |
|---|---:|---:|
| Total / per-panel design lift, N | 94.144 / 47.072 | 101.989 / 50.995 |
| Root shear / root moment | 47.071 N / 15.982 N m | 50.994 N / 17.314 N m |
| 14×12 spar root stress / shear screen | 128.91 / 2.305 MPa | 139.65 / 2.497 MPa |
| Spar tip deflection, E=70 GPa | 38.36 mm | 41.56 mm |
| Spar tip deflection, E=110 GPa | 24.41 mm | 26.45 mm |
| Joiner stress / E=70-GPa centre deflection | 107.04 MPa / .083 mm | 115.96 MPa / .090 mm |

At 2600 g conservative spar-envelope tension/compression/shear screening SFs
are 2.506 / 2.148 / 14.016; nominal values are 4.297 / 3.580 / 24.027.
These are not measured allowables. Root ribs, longitudinal plates and their
configuration remain unchanged; their joint/load-path qualification remains
outstanding.

The E=70-GPa screen exceeds the existing 40-mm deflection STOP. No spar is
changed: qualification requires actual existing Ø14×12 spar **EI >=63.12 N
m²**, equivalent to **E >=72.73 GPa** for its present geometry. Measured EI
qualifies deflection only; it never replaces strength allowables.

The existing 1.25 vertical screen at 2600 g is 63.742 N / 21.642 N m; the
loaded panel in the existing 70/30 split is 71.391 N / 24.239 N m. They remain
sensitivity screens, not new qualification loads.

## Joiner, socket and D-box

At 2600 g, provisional socket screens are: carbon bearing 2.618 MPa (SF
5.729), hoop 16.728 MPa (SF 1.494), birch bearing 7.528 MPa (SF 1.993), birch
net tension 12.546 MPa (SF 1.594), and bond line .301 MPa. These are not
measured allowables; the representative tube/liner/birch/bond proof remains
mandatory.

The existing local socket rule is retained: `1.25 × root design moment` =
**21.642 N m**. Existing 250-mm torque arms require **86.57 N (8.83 kg
equivalent) each**. PASS criteria are unchanged: no slip, crushing, hoop
splitting, delamination or plate cracking, with residual displacement <=.10
mm. This is a socket proof only: do not make a 125% full-wing proof without
limit/ultimate classification and safety review.

The existing worst-|Cm|/lift-offset model at effective G=300 MPa gives:

| Tip twist, degrees | 70 km/h | 90 km/h | 100 km/h | 120 km/h |
|---|---:|---:|---:|---:|
| 2400 g | 1.046 | 1.642 | 1.995 | 2.814 |
| 2600 g | 1.057 | 1.653 | 2.006 | 2.825 |

The exact 2600-g root-equivalent requirement is 22.860 N m², so the practical
reinforced D-box qualification gate is **GJ >=22.9 N m²**. Existing `<=2° @
100 km/h` and `<=3° @120 km/h` gates are unchanged. This is not flutter
substantiation.

## Boom/root transfer, gates and limits

At y=230 mm, mass-dependent 4-g wing background section shear/moment become
32.587 N / 7.717 N m from 30.081 N / 7.123 N m. No new wing-background boom
limiter appears. Published boom/tail aerodynamic, yaw, handling and landing
loads are not scaled by 2600/2400 because their physical assumptions do not
automatically depend on MTOW.

The boom hardpoint remains not release-ready: X coordinate, clamp/fastener
geometry, bond area, bearing/net-section proof and representative mounted test
are TBD. No bolt or attachment geometry is inferred.

Required conditions are: existing spar EI >=63.12 N m² and <=40-mm proof
deflection; representative D-box GJ >=22.9 N m² and existing twist gates;
representative socket proof at 21.642 N m; and every existing dimensional,
strength-evidence, glue, mass and hardpoint gate. Re-run on actual MTOW,
article, geometry, or load-interpretation change. This sensitivity does not
release manufacture, maiden flight, or a changed MTOW.

The maintained material workflow's canonical 2400-g PASS is explicitly
**not transferable** to this 2600-g case: its E>=70-GPa, 19.977-N-m socket,
and 22.8-N-m² D-box gates are below the requirements above. Until these
2600-g-specific values are explicitly evidenced and recorded against the
revalidation artifact, its qualification status is
`UNQUALIFIED_PENDING_2600G_SPECIFIC_EVIDENCE`.

The 70/30 result is an asymmetric sensitivity only, not a proof-load schedule:
its 24.239-N-m loaded-panel moment exceeds the 21.642-N-m symmetric socket
proof, and it therefore cannot be claimed covered by that proof. It reduces
the provisional socket hoop/net SF screens to about 1.07/1.14 and needs a
separate asymmetric case classification before it could govern qualification.
There is no numerical local allowable model for root ribs, longitudinal plates
or their joints; these paths remain unverified/TBD and are covered only by the
existing representative proof and material/joint gates.

For audit, the 2600-g five-zone symmetric 100% full-wing schedule per console
is 12.898, 12.362, 11.212, 9.213 and 5.307 N at y=80, 240, 400, 560 and 720
mm respectively (1.315, 1.261, 1.143, .939 and .541 kg equivalent). It is a
100% current design/limit schedule, not the 125% socket proof.

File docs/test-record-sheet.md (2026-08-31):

# LR1600 physical-test record sheet

Use one block per sample and the same ID in `analysis/materials/measurements.yaml`.

```text
Sample ID: ______________________  Date/time: ______________________
Test family: ____________________  Material / supplier / lot: __________________
Operator: _______________________  Ambient temperature: ______ C
Photo filename(s): ____________________________________________________________
Nominal CAD part: _______________  Actual L x W: __________ x __________ mm
Thickness readings (mm): _____________________________________________________
Carbon tube station / axis (OD, ID, wall, ovality): ___________________________
Joiner rod OD readings / measured tube--rod radial clearance: _________________
Mass before (g): _________________  Mass after cure (if relevant): __________ g
D-box fixture/end-bulkhead mass excluded (g): ______  Complete article mass (g): ______
Scale resolution: ________________  Caliper/micrometer resolution: __________ mm
Fixture / span / arm: _________________________________________________________
Load or torque | dwell | deflection / angle | residual after unload | notes
_______________|_______|____________________|_______________________|______
_______________|_______|____________________|_______________________|______
_______________|_______|____________________|_______________________|______
First slip/damage load: __________ N or N m
Maximum applied load when no failure occurs: __________ N
Mode: [ ] cohesive foam [ ] adhesive [ ] ply delamination [ ] carbon interface
      [ ] split [ ] crush [ ] mixed
Mixed components (at least two family-valid modes): ___________________________
STOP condition seen? __________________________________________________________
Preparation, adhesive, cure/clamp notes: ______________________________________
If projecting glue mass: CAD/assembly bond-area source + areas by family: ______
Raw YAML entry checked: [ ]  SHA-linked summary regenerated: [ ]
```

Record three density IDs per material; for carbon, all 100-mm stations with two
OD/ID values; for D-box, each constituent mass and complete mass. Never replace
an old raw record: create a new sample ID.

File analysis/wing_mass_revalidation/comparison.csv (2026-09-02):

case | mass_g | total_design_lift_n | per_panel_lift_n | root_shear_n | root_bending_moment_nm | spar_root_stress_mpa | spar_tip_deflection_E70_mm | spar_tip_deflection_E110_mm | joiner_stress_mpa | boom_y230_shear_n | boom_y230_moment_nm | dbox_twist_100kmh_deg_G300 | dbox_twist_120kmh_deg_G300
2400g_reference | 2400.0 | 94.14384 | 47.07192 | 47.07114131622687 | 15.981744298832352 | 128.90508764328828 | 38.36278654660364 | 24.41268234783869 | 107.03621972940098 | 30.080575801272808 | 7.123179081650962 | 1.9951421103206959 | 2.8139797649352256
2600g_sensitivity | 2600.0 | 101.98916 | 50.99458 | 50.99373642591247 | 17.313556323735057 | 139.64717828022907 | 41.559685425487324 | 26.447072543491874 | 115.95590470685111 | 32.58729045137886 | 7.7167773384552065 | 2.0063210637158804 | 2.82515871833041

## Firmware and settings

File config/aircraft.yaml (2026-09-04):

project:
  name: LR1600
  units: mm

wing:
  span: 1600
  root_chord: 250
  tip_chord: 200
  airfoil: clark_y
  washout_deg: -1.5
  dihedral_deg: 2.0
  twist_axis_fraction: 0.25
  rib_pitch_mm: 100
  aileron_span_mm: 500
  aileron_chord_mm: 48
  aileron_inboard_offset_mm: 150

spar:
  type: carbon_tube
  outer_diameter: 14
  inner_diameter: 12
  chord_position: 0.30
  hole_clearance_mm: 0.25

materials:
  skin_foam_mm: 3
  rib_foam_mm: 5
  root_rib_plywood_mm: 2.0
  plywood_structural_mm:
    - 2.0
    - 3.0

aircraft:
  # Preliminary integration/design mass case; not a flight-release MTOW.
  target_mass_g: 2600
  design_load_factor_g: 4.0
  gravity_m_s2: 9.80665

# The aircraft reference system applies to every future layout, mass item, and
# CG result.  All coordinates are relative to the root-wing leading edge.
layout:
  coordinate_system:
    datum: wing_root_leading_edge
    x_positive: aft
    y_positive: right
    z_positive: up
    length_unit: mm
    mass_unit: g

# This is intentionally not a first-flight CG approval.  The numerical
# initial/design envelope remains undefined until the tail and stability inputs
# listed in docs/cg-reference.md exist.
cg:
  initial_envelope:
    status: initial_design_assumption
    x_mac_fraction_min: 0.24
    x_mac_fraction_max: 0.28
    basis: preliminary tail-stability-v1 sensitivity; not a measured aircraft CG or first-flight release
  first_flight_recommendation:
    status: preliminary_recommendation
    x_mac_fraction: 0.25
    basis: preliminary tail-stability-v1 conservative point inside the design envelope; requires measured all-up CG before flight

# Preliminary stability integration only.  These values are intentionally
# separated from the immutable wing definition and are not manufacturing data.
tail:
  status: initial_design_assumption
  tail_arm_mm: 650.0
  horizontal:
    span_mm: 700.0
    root_chord_mm: 90.0
    tip_chord_mm: 90.0
    elevator_chord_fraction: 0.40
  vertical:
    fin_height_mm: 230.0
    root_chord_mm: 135.0
    tip_chord_mm: 96.17
    rudder_chord_fraction: 0.30

# Twin-boom reference axes are selected for stability/clearance integration;
# the actual tube section and mass remain design-estimate/TBD until sourced.
booms:
  status: initial_design_assumption
  lateral_offset_mm: 230.0
  axis_z_mm: 0.0
  section_candidate:
    status: tbd
    outer_diameter_mm: null
    inner_diameter_mm: null

# Preliminary powertrain architecture. Envelopes are requirements and simple
# installation volumes, never a commercial motor/ESC/propeller selection.
propulsion:
  status: initial_design_assumption
  nominal_series_count: 6
  propeller:
    diameter_min_mm: 330.2
    diameter_max_mm: 355.6
    pitch_min_mm: 228.6
    pitch_max_mm: 254.0
    cruise_rpm_min: 4500.0
    cruise_rpm_max: 9000.0
  motor:
    kv_min_rpm_per_v: 365.0
    kv_max_rpm_per_v: 570.0
    continuous_electrical_power_w: 550.0
    peak_electrical_power_w: 700.0
    continuous_current_a: 35.0
    peak_current_a: 45.0
    mass_min_g: 120.0
    mass_max_g: 180.0
    envelope_length_mm: 70.0
    envelope_diameter_mm: 50.0
  esc:
    # Mirror of the current preliminary hardware manifest installation box.
    length_mm: 73.0
    width_mm: 30.0
    height_mm: 12.0
    x_mm: 285.0
    y_mm: 42.0
    z_mm: 5.0
  propeller_plane_x_mm: 430.0
  motor_cg_x_mm: 395.0
  motor_axis_z_mm: 50.0

# Propulsion and avionics rails are intentionally independent. Values are
# preliminary electrical requirements, not a selected ESC/BEC or pack curve.
electrical:
  status: initial_design_assumption
  propulsion_bus_nominal_voltage_v: 22.2
  propulsion_bus_loaded_min_voltage_v: 21.0
  avionics_logic_rail_v: 5.0
  servo_rail_v: 6.0
  hotel_load_low_w: 7.0
  hotel_load_nominal_w: 16.0
  hotel_load_high_w: 25.0

# Battery data reserves a removable-pack envelope. The Li-ion direction is
# conditional on verified cells/parallel-count sag and peak-current evidence.
battery:
  status: initial_design_assumption
  chemistry_direction: li_ion_preliminary
  # P60B 6S1P preliminary branch: 129.6 Wh nominal, 103.7 Wh study usable,
  # 503 g complete-pack estimate. The physical pack/tray remains a design
  # estimate until the actual build is weighed and its removal route is proven.
  usable_energy_preferred_min_wh: 103.7
  usable_energy_preferred_max_wh: 103.7
  mass_min_g: 490.0
  mass_max_g: 520.0
  package_length_mm: 155.0
  package_width_mm: 75.0
  package_height_mm: 28.0
  # Preliminary ledger solution, not an installation clearance pass: a long
  # forward bay is deliberately retained to close the 24--28% MAC study.
  nominal_x_mm: -370.0
  x_adjustment_min_mm: -387.5
  x_adjustment_max_mm: -332.5
  y_mm: 0.0
  z_mm: 0.0
  tray_status: preliminary_design_assumption
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

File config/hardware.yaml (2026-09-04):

# Commercial implementation manifest.  Aircraft geometry and requirements stay
# in aircraft.yaml; values here are preliminary hardware evidence, not a
# procurement release.  All dimensions/positions use the root-wing-LE datum.
schema: lr1600-hardware-baseline-v2
status: preliminary_integration_hardware_with_required_bench_and_installation_validation

components:
  - id: propulsion_motor
    category: propulsion
    status: design_estimate
    manufacturer: null
    model: 6S pusher motor class, MN4014-400 or equivalent; SKU TBD
    source_url: null
    source_retrieved_date: null
    mass_g: 145.0
    mass_status: design_estimate
    dimensions_mm: {length: 70.0, width: 50.0, height: 50.0}
    position_mm: {x: 395.0, y: 0.0, z: 50.0}
    limits: {kv_rpm_per_v: 400.0, series_cells: '6S', continuous_current_a_180_s_with_cooling: 45.0, continuous_power_w_180_s_with_cooling: 700.0, shaft_diameter_mm: 4.0, mount_pattern_mm: 'TBD; adapter plate envelope', mass_range_g: [120.0, 180.0]}
    notes: 'Dimensional/mass class only, not a procurement lock. Bench-map the selected motor with the selected 13x10 pusher, including cooling, current, thrust, vibration and adapter retention.'
  - id: propulsion_propeller
    category: propulsion
    status: design_estimate
    manufacturer: null
    model: 13x10 electric pusher; SKU TBD
    source_url: null
    source_retrieved_date: null
    mass_g: 28.0
    mass_status: design_estimate
    dimensions_mm: {length: 330.2, width: 12.0, height: 330.2}
    position_mm: {x: 430.0, y: 0.0, z: 50.0}
    limits: {diameter_in: 13.0, pitch_in: 10.0, blades: 2, hub_diameter_mm: tbd, shaft_pilot_mm: tbd, safe_rpm: tbd_verify_selected_propeller_limit, mass_range_g: [24.0, 32.0]}
    notes: 'Preferred baseline. Install as a true pusher with positive adapter/nut retention; selected propeller RPM limit and installed operating point remain unvalidated.'
  - id: propulsion_propeller_fallback
    category: propulsion
    status: fallback
    manufacturer: APC
    model: 14x10 electric pusher secondary integration case
    source_url: null
    source_retrieved_date: '2026-09-01'
    mass_g: null
    mass_status: tbd
    dimensions_mm: {length: null, width: null, height: null}
    position_mm: {x: null, y: null, z: null}
    limits: {diameter_in: 14.0, pitch_in: 10.0, blades: 2, use_limit: 'secondary integration case only'}
    notes: 'Not included in mass or rough-field clearance baseline.'
  - id: propulsion_esc
    category: propulsion
    status: selected_preliminary
    manufacturer: Hobbywing
    model: Skywalker 60A V2 / 30216101
    source_url: https://www.hobbywing.com/en/uploads/file/20250930/64b726be7a56c9f415385f77683cdc46.pdf
    source_retrieved_date: '2026-09-01'
    mass_g: 68.0
    mass_status: datasheet
    dimensions_mm: {length: 73.0, width: 30.0, height: 12.0}
    position_mm: {x: 285.0, y: 42.0, z: 5.0}
    limits: {series_cells: '3-6S LiPo', continuous_current_a: 60.0, burst_current_a: 80.0, integrated_bec: '5V 7A; intentionally unused', telemetry: tbd}
    notes: 'Installed cooling and current margin require pusher bench validation; no telemetry claim is made.'
  - id: flight_battery
    category: energy_storage
    status: selected_preliminary
    manufacturer: Molicel / integration build
    model: INR-21700-P60B 6S1P preliminary complete pack
    source_url: https://www.molicel.com/inr-21700-p60b/
    source_retrieved_date: '2026-09-03'
    mass_g: 503.0
    mass_status: design_estimate
    dimensions_mm: {length: 155.0, width: 75.0, height: 28.0}
    position_mm: {x: -370.0, y: 0.0, z: 0.0}
    limits: {topology: 6S1P, cells: 6, nominal_voltage_v: 21.6, nominal_energy_wh_typical: 129.6, usable_energy_wh_at_80_percent: 103.7, cell_continuous_current_a: tbd, pack_current_a_broad_screen: tbd, mass_range_g: [490.0, 520.0]}
    notes: '503-g complete-pack integration estimate. X=-370.0 mm is the preliminary no-ballast 25%-MAC rail index from the unified design ledger; the 155x75x28 envelope is a packaging estimate, not a vendor drawing. Pack dimensions/mass, cold/sag behaviour, retention and hatch removal remain validation gates.'
  - id: aileron_servo_left
    category: servo
    status: design_estimate
    manufacturer: KST
    model: lightweight metal-gear micro-servo class; final SKU TBD
    source_url: null
    source_retrieved_date: null
    mass_g: 8.0
    mass_status: design_estimate
    dimensions_mm: {length: 24.0, width: 12.0, height: 24.0}
    position_mm: {x: 135.0, y: -450.0, z: 0.0}
    limits: {rail_v: '6.0', torque_kgf_cm_at_6v: tbd, speed_s_per_60deg_at_6v: tbd, stall_current_a_at_6v: tbd}
    notes: 'Quality micro-servo class only; close selected SKU and aileron hinge-moment/current validation before procurement.'
  - id: aileron_servo_right
    category: servo
    status: design_estimate
    manufacturer: KST
    model: lightweight metal-gear micro-servo class; final SKU TBD
    source_url: null
    source_retrieved_date: null
    mass_g: 8.0
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

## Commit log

2026-08-30 Initialize LR1600 CAD toolchain
    [rib_00_root.dxf, rib_01_station_100.dxf, rib_02_station_200.dxf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]
2026-08-30 analysis: validate Clark Y aerodynamics
    [clarky_re120000_clean.csv, clarky_re120000_realistic_model.csv, clarky_re120000_realistic_model_combined.csv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]
2026-08-31 feat: add CAD preview workflow
2026-08-31 chore: pin LR1600 specialist agent models
2026-08-31 analysis: validate LR1600 wing structure
    [distributed_load.csv]
2026-08-31 test: add LR1600 material validation workflow
    [DBOX-A-BIRCH2-CLOSURE.dxf, DBOX-A-BIRCH3-END-BULKHEAD.dxf, DBOX-A-FOAM3-LOWER-SKIN.dxf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]
2026-08-31 docs: record local laser workflow limits
2026-08-31 feat: integrate LR1600 tail boom stability
    [aircraft.yaml, config.py]
2026-09-01 feat: add LR1600 powertrain packaging architecture
2026-09-01 fix: clear LR1600 battery travel packaging
    [aircraft.yaml]
2026-09-01 test: validate LR1600 battery travel clearance
2026-09-01 feat: add LR1600 hardware baseline closure
    [hardware.yaml]
2026-09-02 analysis: revalidate LR1600 wing at 2600g
    [comparison.csv, mass_sensitivity_2400_2600.csv]
2026-09-03 Add fuselage gear and CG integration v1
    [hardware.yaml]
2026-09-03 fix: correct wing rib trailing-edge contours
    [rib_00_root.dxf, rib_01_station_100.dxf, rib_02_station_200.dxf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]
2026-09-03 fix: use fixed nose gear architecture
    [hardware.yaml]
2026-09-04 Пуш с блоккером
    [DBOX-A-BIRCH2-CLOSURE.dxf, DBOX-A-BIRCH3-END-BULKHEAD.dxf, DBOX-A-FOAM3-LOWER-SKIN.dxf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]
2026-09-04 wip: record fuselage CAD convergence v2 blockers
    [DBOX-A-BIRCH2-CLOSURE.dxf, DBOX-A-BIRCH3-END-BULKHEAD.dxf, DBOX-A-FOAM3-LOWER-SKIN.dxf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]
2026-09-04 wip: converge fuselage joints and assembly v3
2026-09-04 wip: validate fuselage skeleton assembly v4
